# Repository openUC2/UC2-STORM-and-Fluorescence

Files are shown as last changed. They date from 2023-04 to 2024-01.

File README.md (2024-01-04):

# U.C.*STORM*
---

**Overview:**
Fluorescence microscopy is pivotal in life sciences. However, the high cost and complexity of advanced equipment limit its widespread adoption. While open-source scientific hardware offers promising solutions, they often compromise on image quality. To bridge this gap, we introduce the UC2 microscopy toolbox.

**Key Features:**
- **Cost-Effective & High-Quality**: Integrates affordable components with state-of-the-art electronics and software for top-notch fluorescence microscopy.
- **Versatile Imaging**: Achieves high-resolution fluorescence imaging for both fixed and live samples. Enables long-term live-cell imaging when placed in an incubator.
- **Advanced Imaging Capabilities**: Attains single molecule sensitivity, supports single particle tracking, and SMLM super-resolution microscopy experiments within cells.
- **Open-Source Software**: Delivers high-quality scientific data generation for both novices and experts at a fraction of commercial system costs.

**Impact & Use Cases:**
Ideal for laboratories with budget constraints, this cost-effective solution matches the capabilities of pricier commercial systems. Moreover, its affordability and ease of use make it an excellent teaching tool for students.

This repository will help you to build *a widefield fluorescence microscope and show you how to upgrade it to perform advanced microscopy methods, such as (d)STORM*.

## Cite this article

You can find the article currently as a [biorxiv Preprint](https://doi.org/10.1101/2023.05.31.542706):

```
An open-source, high resolution, automated fluorescence microscope
Ando C. Zehrer, Ana Martin-Villalba, Benedict Diederich, Helge Ewers
bioRxiv 2023.05.31.542706; doi: https://doi.org/10.1101/2023.05.31.542706
```

## How does it look like?

## 3D View

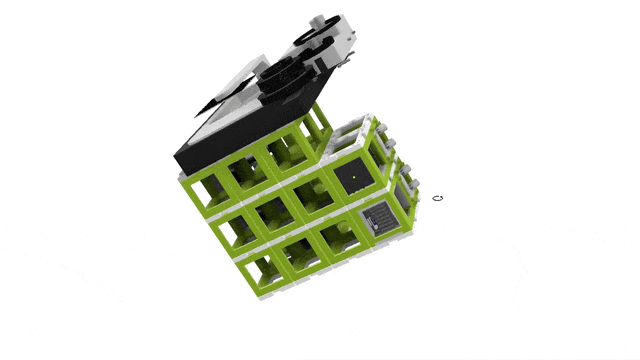
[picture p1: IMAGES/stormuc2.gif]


### Top View

<p align="center">
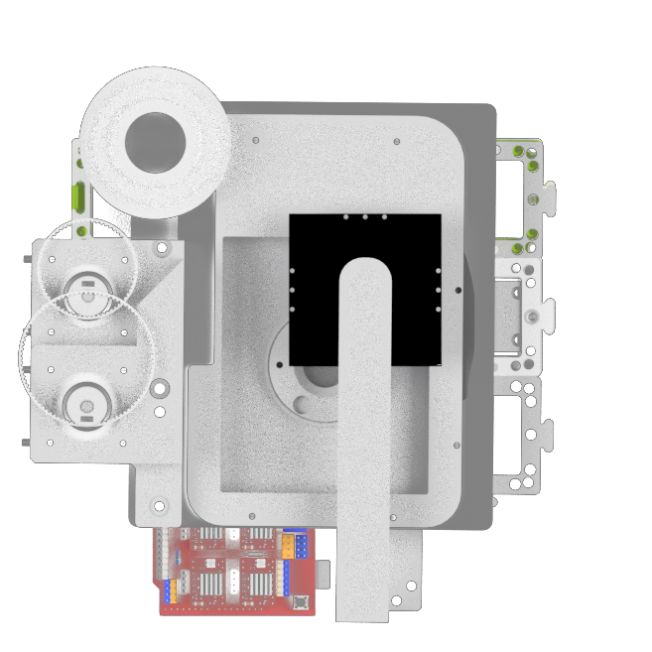
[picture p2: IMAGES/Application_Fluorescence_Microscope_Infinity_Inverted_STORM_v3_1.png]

</p>

### Side View

<p align="center">
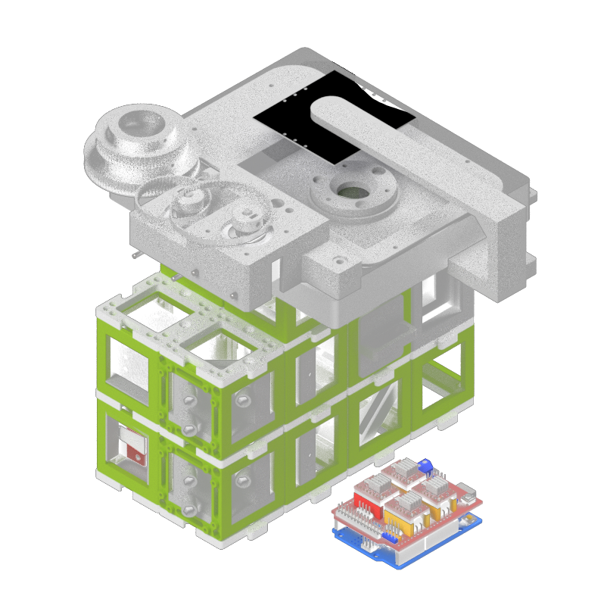
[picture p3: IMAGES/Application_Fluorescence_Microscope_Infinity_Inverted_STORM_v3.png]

</p>

***Features:***
* Single-channel fluorescence imaging
* Bright-field imaging
* XYZ motorized automated microscopy
* LED Matrix for quantitative imaging
* Steering fully integrated into ImSwitch

## Assembly

Certainly! The instructions you provided seem like a comprehensive guide to building a single molecule localization microscope using the modular optical system UC2. Below, I've expanded on a few aspects to ensure that the steps are clear and more detailed, providing information about some safety precautions, required materials, and additional tips.

### Possible to assemble in <2 Minutes 


Obviously, adjusting the lenses and mirrors, as well as adapting self-made 3D printed parts will take some time. However, the framework of the microscope is rapid and simple to build. The cubes can simply be stuck together to get the outlay of the microscope in few minutes. This allows to swiftly exchange modules, make changes and even replace components.

### Microscope Building Instructions


**Building the UC2 widefield microscope: a.** Photograph of the finished setup. **b.** Photograph of all single pieces of the dismanteled setup. The bill of materials lists all these components, including CAD files for the 3D printed parts. **c.** Emission pathway of the microscope. **d.** Stability increased by using a layer of puzzles below and above the cubes. **e.** CAD schematic of the emission pathway. **f.** Excitation pathway of the microscope. **g.** Excitation layer is also covered by a puzzle layer. **h.** CAD schematic of the excitation pathway. **i.** Z-stage photograph and corresponding CAD file. **j.** Empty cubes work as place-holder between the excitation layer and the microscope stage. **k.** The objective is screwed into the objective holder. **l.** By wiring the electronica the stage is ready to use and the microscope functional (see photograph in **a.**).



#### 0. Introduction and Precautions

Before we begin, make sure that you are working in a well-ventilated area and wearing appropriate safety gear, such as goggles and gloves. Handling lasers requires caution, so follow the manufacturer's guidelines and take necessary safety measures.

#### Materials and Tools Needed:

- UC2 modular optical system components
- Camera with the compatible mounting system
- Achromatic lens with a suitable mount
- 3D printer (for creating mounts)
- Thorlabs 20mm tube or equivalent
- Laser with adaptable profile
- Convex lenses
- Diffuser (cling foil, etc.)
- Motor-driven translation stage
- 3D printed gears and timing belts
- Commercial XY stage
- 4-well/8-well chambers and circular 18 mm/25 mm cover glass holders
- Alignment tools, such as apertures
- LED for top-light illumination
- Various screws, bolts, and tools for assembly
- Protective gear for handling lasers and other delicate components

#### 1. Detection Layer

The schematic of the layer and the actual composition can be seen in the **setup building figure**.
The camera is positioned within a cube, so that the camera chip is
centered. At a distance of 100 mm, the tube lens is positioned on the
same optical axis. As a cube is 50 mm broad, an empty cube is placed
between the camera and the lens. A 3D printed mount is combined with a
Thorlabs 20 mm tube, to which a mounted achromatic lens can be screwed
to the tube. The 3D printed mount is thick enough to not tilt while
still being movable. The 3D printed mount holding the lens is moved to
focus an object on the camera. The mirror can be placed in front of the
camera or before the tube lens. The mirror is tiltable along two axes.
The emissions from the objective are parallel. The distance can be
chosen accordingly to the build. A mirror tilted by 45 degrees reflects
the vertical emissions of the sample into the tube lens and subsequently
onto the camera.
<!---
![](./IMAGES/image1.png)

Emissions from the objective are reflected by the mirror, focused by the
tube lens, displaced with the tiltable mirror and imaged on the
detector.
--->
#### 2. Laser

The laser profile can be tuned to match the application the microscope
will be used for. When imaging a Chroma red fluorescent slide, the laser
profile can be characterized, and possible variations or inhomogenities can be removed.
Without any modification, the laser only
illuminates a subset of the field of view. By adding a telescope build,
the laser beam is magnified. The modifications proposed in the **Illumination** section show different illumination patterns, leading to different possible imaging modalities.

<!---
![](./IMAGES/image2.png)

![](./IMAGES/image3.png)

![](![](./IMAGES/image4.png)

![](![](./IMAGES/image5.png)

Here, the lens l1 is focusing onto the rotating cling foil. The diffused beam is magnified by the lens l2. The
resulting beam profiles can be seen in following images:

The laser beam without magnification (left) has a smaller spot with high
laser intensity. The illumination is not homogeneous but can be
advantageous for applications needing higher laser densities. The laser
profile with a 2 times magnification (middle) and the magnification with
diffuser (right) enable homogeneous illumination of most of the field of
view.
--->
##### Tips:

- Ensure that the diffuser is balanced properly to avoid vibrations that might affect the image quality.
- Calibration of the laser profile according to the application is crucial. Make sure to test different magnifications and diffusions.

#### 3. Excitation Layer

The laser emission can be chosen accordingly. The laser beam is then
focused by a lens into the back focal plane of the objective (here after
the filter cube in a higher vertical plane). Through a tiltable mirror,
the beam can be positioned into the center of the field of view. The
filter cube has filters adapted to the laser and the fluorophores used
in the experiments. The mount for the laser, the lens, the mirror as
well as the filter cube can all be 3D printed. The schematic and actual photograph of the layer within the setup are shown in the **setup building figure**.
<!---
![](./IMAGES/image6.png)
--->

##### Tips:

- Ensure that all 3D printed components fit perfectly with the rest of the parts.
- The choice of filters must correspond with the laser and the fluorophores used in the experiments.

#### 4. Z Stage
<!---
![](./IMAGES/image7.png)
--->
The z stage is a motor driven translation stage. The
stage is embedded into a 3D printed case to make the dimensions fit the
cube design. A puzzle piece on the top and in the bottom allow to build
a stable connection between the stage and the rest of the microscope. A
3D printed objective holder connects the stage to the objective. It is
advised to print the objective holder with a high percentage of infill
and a stable plastic, as the heavy objective causes strain on the
material.

##### Tips:

- Careful selection of the material for the objective holder is crucial to withstand the weight and strain.

#### 5. XY Stage

The XY stage used in the current build is a commercial solution. The
manual translation knobs were equipped with 3D printed gears. In order
to motorize the stage, motors which were also equipped with gears
transmitted the torque to the stage via timing belts. These were printed
with a softer and thus more elastic plastic. The whole stage is attached
to the rest of the microscope via a 3D printed plate, working as a
replacement for a puzzle layer, with the according perforations where
connections to the top layer of cubes was provided. Furthermore, the
stage needs a 3D printed insert, to hold the sample. Models for
4-well/8-well chambers and circular 18 mm/25 mm cover glass holders are
available. An alternative where the coverglass is directly embedded into
the 3D printed sample holder is also provided.

##### Tips:

- Calibration and testing of the XY stage should be done to ensure smooth and accurate movement.

#### 6. Alignment Procedure

To align the optics, the first step is to position all optics along the
optical axis and ensure that they are not tilted. To make this procedure
more systematic, the excitation pathway is aligned with an aperture,
which is placed between the second lens of the telescope build and the
lens focusing the laser in the back focal plane of the objective. While
imaging a fluorescent slide, an almost closed aperture is placed to
match the maximum of the laser excitation. This allows to know the
position of the laser within the sample. The emission pathway is then
adjusted to have the aperture in the center of the field of view. This
way, the maximal laser intensity spot is in the center of the field of
view, which should both theoretically be along the optical axis.

##### Tips:

- Proper alignment is essential for obtaining accurate results. Take your time and follow systematic procedures.
- Specialized alignment tools and techniques might be needed for precise adjustments.

#### 7. Top Light Illumination

The illumination for bright-field imaging needs to be spatially
invariant in relation to the objective. It is important to attach the
top-light illumination to the main body of the microscope instead of the
XY stage. This is achieved by attaching an LED to a 3D printed arm,
connected to the highest puzzle layer, thus decoupled of the possible
motions of the XY-stage.

##### Tips:

- The brightness of the LED should be adjustable to suit various imaging requirements.
- Consider using a diffuser to create more uniform illumination across the sample.

### Conclusion

Building a single molecule localization microscope with the modular optical system UC2 is an exciting and challenging project. This guide provides a step-by-step approach to construct the microscope and align its various components. Always remember to follow safety precautions and consult manufacturer's guidelines or a professional if you are unsure about any step.

Feel free to share your progress and ask questions on GitHub or other platforms, as the scientific community can be of great assistance in such projects.

Happy building!

## Bill of material

Below you will find all components necessary to build this device

### 3D printing files

All these files need to be printed. We used a Prusa i3 MK3S using PLA Prusament (Galaxy Black) at layer height 0.15 mm and infill varying between 20-40 %, depending on how much weight rests on the 3D printed part. For applications within the incubator, the use of ABS Prusament is recommended, as the thermal stability is noticeably increasing the setups stability, especially with increased working temperature and humidity. The layer height and the infill can be chosen identically for ABS as for PLA parts.

An in-depth tutorial on how to build the XY-stage can be found here https://github.com/openUC2/

An in-depth tutorial on how to build the Z-stage can be found here https://github.com/openUC2/

| Printed  | UC2 | Linear Stage mount | 00_Linear_Stage_NEMA11_Mount.ipt | 1  | $5.00 | 5 |
|---|---|---|---|----|---|-----|
| IM | openUC2 | openUC2 IM Cube | 10_Cube_1x1_IM.ipt | 42 | $5.00 | 210 |
| IM | openUC2 | UC2 Puzzle piece | 10_Base_puzzle_v3.ipt | 26 | $5.00 | 130 |
| Printed  | UC2 | Linear Stage spacer | 00_Linear_Stage_NEMA11_Mount_Lid.ipt | 1  | $1.00 | 1 |
| Printed  | UC2 | UC2 objective Mount linear stage | 20_Cube_Insert_Cube_Z-Stage_NEMA11_china_objectivemount_v3.ipt | 1  | $1.00 | 1 |
| Printed  | UC2 | UC2 Insert for Kinematic Mirror Part1 | 20_Cube_Insert_Kinematic_Mirrormount_45_base_part1.ipt | 3  | $5.00 | 15  |
| Printed  | UC2 | UC2 Insert for Kinematic Mirror Part2 | 20_Cube_Insert_Kinematic_Mirrormount_45_base_part2.ipt | 3  | $1.00 | 3 |
| Printed  | UC2 | Adapter for Nut | 30_Adapter_M3_nut.ipt | 9  | $1.00 | 9 |
| Printed  | UC2 | UC2 Insert for 1 inch Mirror, 45° | 20_Cube_Insert_Kinematic_Mirrormount_45_Thorlabsadapter.ipt | 3  | $5.00 | 15  |
| Printed  | UC2 | UC2 Insert for standard C-mount | 20_Cube_Insert_Cmount_v3.ipt | 1  | $5.00 | 5 |
| Printed  | UC2 | UC2 Insert for Thorlabs Cage | 20_Cube_Insert_Thorlabs_Pins.ipt | 2  | $5.00 | 10  |
| Printed  | UC2 | UC2 Insert for Thorlabs 1inch lens | 20_Cube_Insert_Thorlabs_SM1Tube.ipt | 2  | $5.00 | 10  |
| Printed  | UC2 | Filtermount | 30_Cube_Insert_Filter_Revolver_Filter_base_single_v3.ipt | 1  | $5.00 | 5 |
| Printed  | UC2 | UC2 Insert for Allied Vision Camera | 30_XYTabel_Aliexpress_basplateadapter.ipt | 1  | $7.00 | 7 |
| Printed  | UC2 | Motormount for XY Stage | 30_XYTable_Aliexpress_motormount.ipt | 1  | $7.00 | 7 |
| Printed  | UC2 | Sample Inset for XY Stage | 30_XYTable_Aliexpress_sampleinsert_round.ipt | 1  | $7.00 | 7 |
| Printed  | UC2 | Timing Gear Small | 00_XYTable_medium_gear.ipt | 1  | $2.00 | 2 |
| Printed  | UC2 | Timing Gear Large | 00_XYTable_large_gear.ipt | 1  | $2.00 | 2 |
| Printed  | UC2 | Printed Timing Belt Long | 00_GT2_TimingBelt_flexible_Modular_xytable_large_89tooth.ipt | 1  | $5.00 | 5 |
| Printed  | UC2 | Printed Timing Belt Short | 00_GT2_TimingBelt_flexible_Modular_xytable_large_65tooth.ipt | 1  | $5.00 | 5 |
| Printed  | UC2 | Holder for LED Array | 40_Cube_XY_Table_Illumination_Arm.ipt | 1  | $5.00 | 5 |
| External | Adafruit | Adafruit 64 LED array (8x8) | 00_LED-ARRAY.ipt | 1  | $20.00  | 20  |
| External | Chroma | Chroma ET655 | 00_Chroma_ET655lp long-pass.ipt | 1  | $250.00 | 250 |
| External | Chroma | Chroma ZET 636 | 00_Chroma ZET635_Excitationfilter.ipt | 1  | $250.00 | 250 |
| External | Chroma | Chroma ZT640 | 00_Chroma_ZT640rdc.ipt | 1  | $250.00 | 250 |
| External | Any provider | Linear Stage 50mm , Nema 12, MGN9h | | 1  | 50 | 50  |
| External | Any provider | 5 mm Neodym Magnets | 00_BallMagnets_5mm_single.ipt | 9  | | 0 |
| External | Thorlabs | Thorlabs PF 10-03-P01 | 00_Thorlabs_PF10-03-P01-Step.ipt | 3  | $25.00  | 75  |
| External | Allied Vision | Allied Vision Alvium USB 3.1 Kamera 1800 U-158m, 1/2,9", 1,58 MP, C-Mount, monochrom | *Varies* | 2  | $445.00 | 890 |
| External | | C:\cad\PSP2011Client\Work\139705407318IP01941702.stp | 00_Basler_ace_USB3_C-Mount.ipt | 1  | | 0 |
| External | Würth | DIN 912 - M3 x 0.5 x 12 x 10.75.ipt | DIN 912 - M3 x 0.5 x 12 x 10.75.ipt | 15 | $1.00 | 15  |
| External | Thorlabs | Thorlabs AC254-050-A-ML | 00_THORLABS_AC254-050-A-ML-Step.ipt | 2  | $100.00 | 200 |
| External | Thorlabs | Thorlabs CP33 | 00_Thorlabs_Cage_CP33_M.ipt | 2  | $20.00  | 40  |
| External | Euromex | Euromex Mechanischer 180 x 155 mm Objekttisch mit integriertem 75 x 55 mm X-Y-Kreuztisch und transparenter Glasplatte, NZ.9505 | 00_XYTable_china_75_55mm.ipt | 1  | $200.00 | 200 |
| External | Robot kit | GT2 pulley 16 teeth 4mm bore for 6mm timing belt | 00_XYTable_pulley.ipt | 2  | $2.00 | 4 |
| External | Laserlands.net  | 638nm Red Laser Module 500mW Round Dot Focusable TTL 3050 | 00_LASER_640nm.ipt | 1  | $40.00  | 40  |

### Design files

The original design files are in the [INVENTOR](./INVENTOR) folder.

## Showcase
The compact size of the setup and the modular character allow to adapt the setup to any incubator. ImSwitch can be started from any given compute ror laptop. Simple USB cables connect the microscope to the outside (computer) for full control over its functionalities.
Here you can see the device in action:

<p align="center">
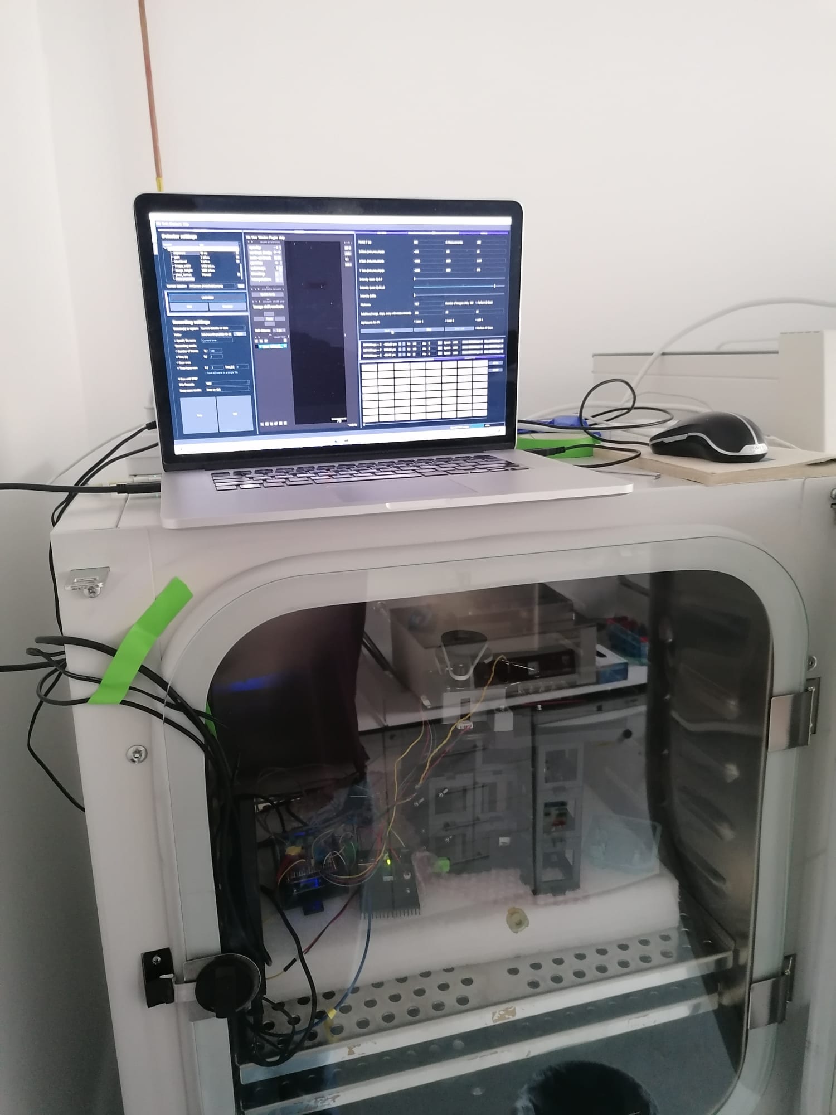
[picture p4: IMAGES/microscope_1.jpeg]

</p>gith

Example of the setup being used within a cell culture incubator for continuous imaging of cells.

<p align="center">
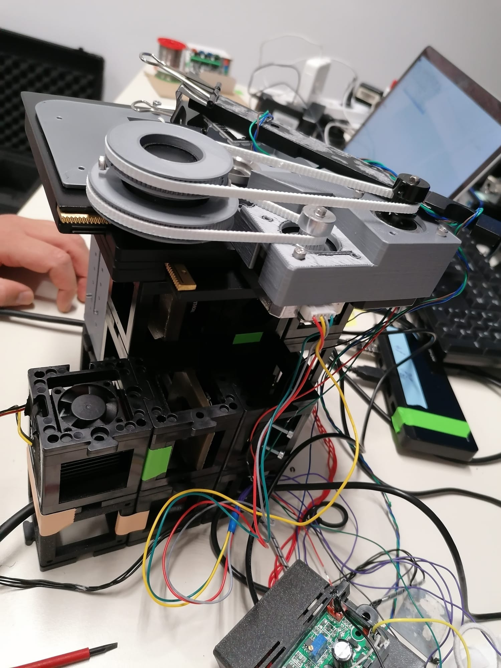
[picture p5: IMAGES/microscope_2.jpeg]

</p>

<p align="center">
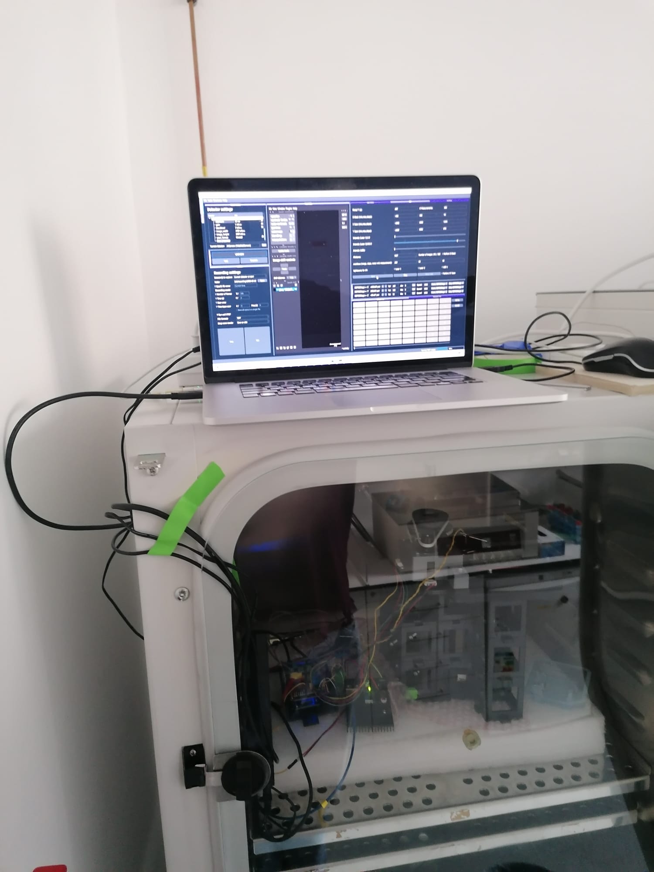
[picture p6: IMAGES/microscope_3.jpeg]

</p>

<p align="center">
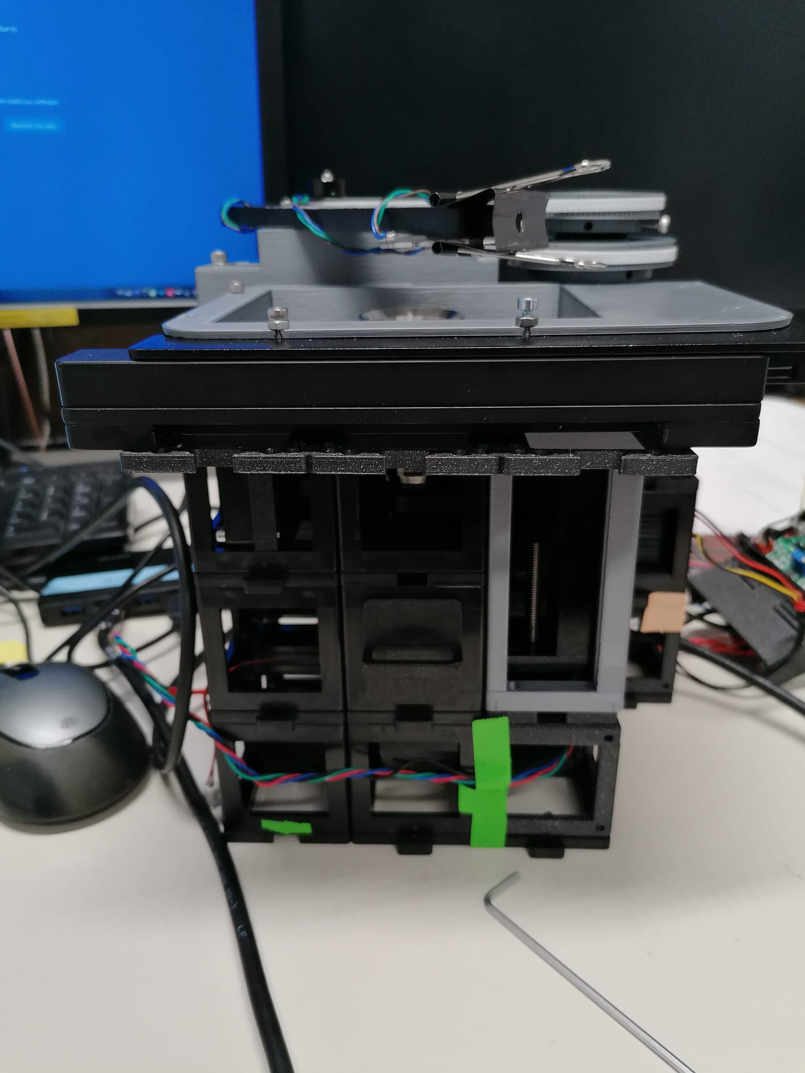
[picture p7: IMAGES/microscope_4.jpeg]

</p>

<p align="center">
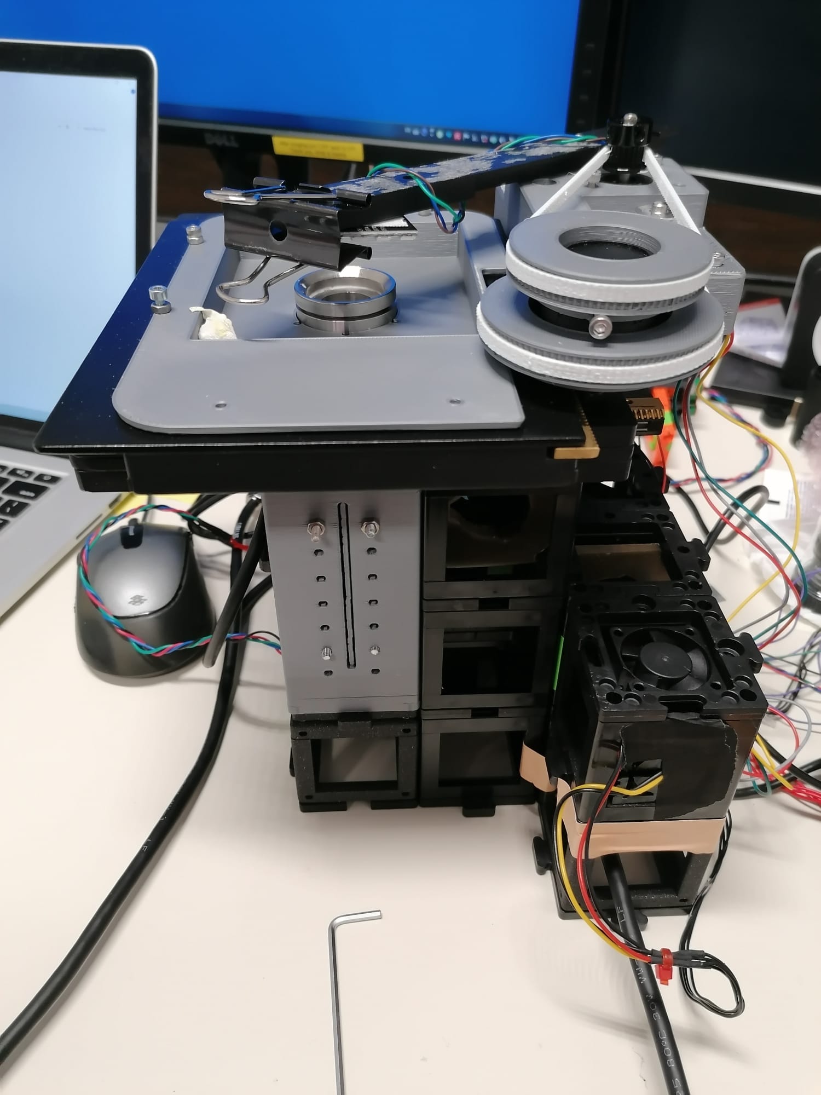
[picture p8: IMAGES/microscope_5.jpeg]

</p>

<p align="center">
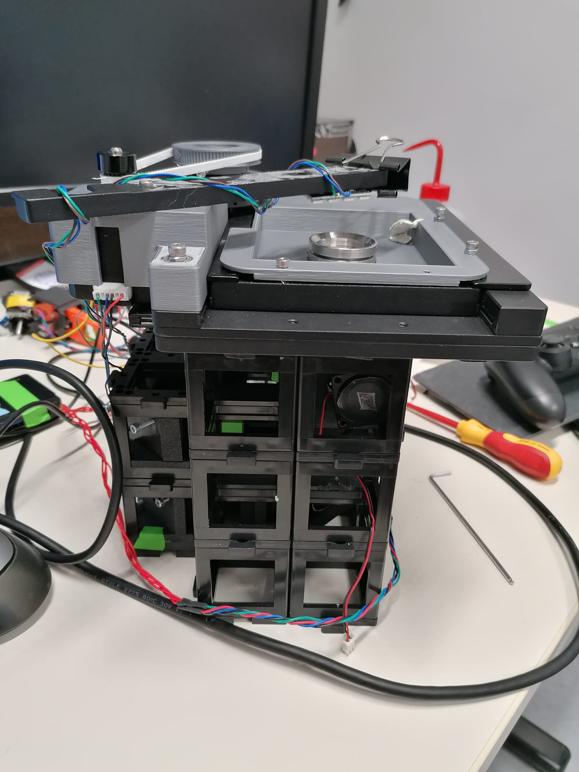
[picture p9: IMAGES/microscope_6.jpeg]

</p>

## Mechanical stability of the setup

See the mechanical stability section of the repository.

## Wide-field imaging, Live-cell imaging, Single molecule applications

See the Results section of the repository.

## Get Involved

This project is open so that anyone can get involved. You don't even have to learn CAD designing or programming. Find ways you can contribute in  [CONTRIBUTING](https://github.com/openUC2/UC2-GIT/blob/master/CONTRIBUTING.md)

## License and Collaboration

This project is open-source and is released under the CERN open hardware license. Our aim is to make the kits commercially available.
We encourage everyone who is using our Toolbox to share their results and ideas, so that the Toolbox keeps improving. It should serve as a easy-to-use and easy-to-access general purpose building block solution for the area of STEAM education. All the design files are generally for free, but we would like to hear from you how is it going.

You're free to fork the project and enhance it. If you have any suggestions to improve it or add any additional functions make a pull-request or file an issue.

Please find the type of licenses [here](https://github.com/openUC2/UC2-GIT/blob/master/License.md)

REMARK: All files have been designed using Autodesk Inventor 2019 (EDUCATION)

## Collaborating
If you find this project useful, please like this repository, follow us on Twitter and cite the webpage or the publication! :-)

<!---
# Unsorted Images
![](./IMAGES/Application_Fluorescence_Microscope_Infinity_Inverted_STORM_v3.png)
![](./IMAGES/Application_Fluorescence_Microscope_Infinity_Inverted_STORM_v3_1.png)
![](./IMAGES/Folie1.png)
![](./IMAGES/image1.png)
![](./IMAGES/image2.png)
![](./IMAGES/image3.png)
![](./IMAGES/image4.png)
![](./IMAGES/image5.png)
![](./IMAGES/image6.png)
![](./IMAGES/image7.png)
![](./IMAGES/IMG_20200803_092845.jpg)
![](./IMAGES/IMG_20200803_093507.jpg)
![](./IMAGES/IMG_20200803_093543.jpg)
![](./IMAGES/IMG_20200803_094150.jpg)
![](./IMAGES/IMG_20200803_124932.jpg)
![](./IMAGES/IMG_20200807_181322.jpg)
![](./IMAGES/IMG_20200807_181333.jpg)
![](./IMAGES/IMG_20200807_181517.jpg)
![](./IMAGES/IMG-20200803-WA0003.jpeg)
![](./IMAGES/microscope_1.jpeg)
![](./IMAGES/microscope_2.jpeg)
![](./IMAGES/microscope_3.jpeg)
![](./IMAGES/microscope_4.jpeg)
![](./IMAGES/microscope_5.jpeg)
![](./IMAGES/microscope_6.jpeg)
![](./IMAGES/STORM.gif)

![](./IMAGES/UC2_STORM.png)
![](./IMAGES/SetupImages_1.jpeg)
![](./IMAGES/SetupImages_2.jpeg)
![](./IMAGES/SetupImages_3.jpeg)
![](./IMAGES/SetupImages_4.jpeg)
![](./IMAGES/SetupImages_5.jpeg)
![](./IMAGES/SetupImages_6.jpeg)
--->

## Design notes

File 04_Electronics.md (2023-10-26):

# Electronics

Here we make use of the ESP32 Wemos D1 R32 microcontroller board in combination with the CNC Shield v3. The wiring of the different components is straight forward as the Stepper Motors are attached to the stepper drivers and the Laser is triggered by the `SpinEn` pin. The NeoPixel LED mounts to the  `Hold` pin.



## Flashing the firmware

Go to the website https://youseetoo.github.io/ and choose the CNC board as the hardware configuration to flash the latest version of the Firmware. The PS3 controller's MAC address has to be setup with the PS Pairing tool. The actual MAC Address is printed out on the Serial monitor while the Board is booting up.

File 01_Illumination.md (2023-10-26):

# Setting up the laser

## Laser illumination

Illuminating the sample can be done with different lasers. In the here
presented setup, the laser illumination is provided by the 638nm Red
Laser Module 500mW Round Dot Focusable TTL 3050 (acquired on
lasernets.com). In order to perform imaging assays needing high laser
intensities, the laser path remains unchanged (see excitation pathway
figure) to maximize the photon density at the sample plane. The optional
beam magnifier combined with a diffuser enables to have a more even and
homogenized illumination across the field of view, which is more
desirable for imaging assays with lower requirements in terms of laser
density.

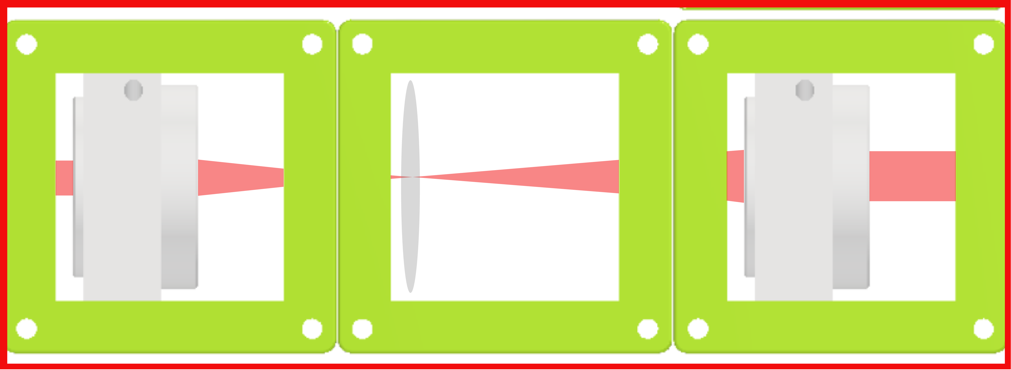
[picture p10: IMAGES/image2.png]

The telescope is built by placing two
convex lenses in a distance equal to the sum of their focal distances in
the light path. The magnification can then be calculated by the ratio of
the focal lengths (e.g. f1 = 3\*f2 magn. = 3x). If the beam is not
homogeneous or does not have a smooth profile or patterns that vary over
time, the beam can be homogenized through diffusing the light in the
common focal point of both telescope lenses. The diffuser can be as
simple as a cling foil, attached to a rotor or a fan motor and spinning
the foil.

A photograph of the construction consisting of a telescopic lens arrangement with a
diffusor rotating in the focal point of both lenses is showed in the figure below. A simplified
version can be built by combining a fan, where the rotor blades have
been removed, with a piece of cling foil as diffusing material.

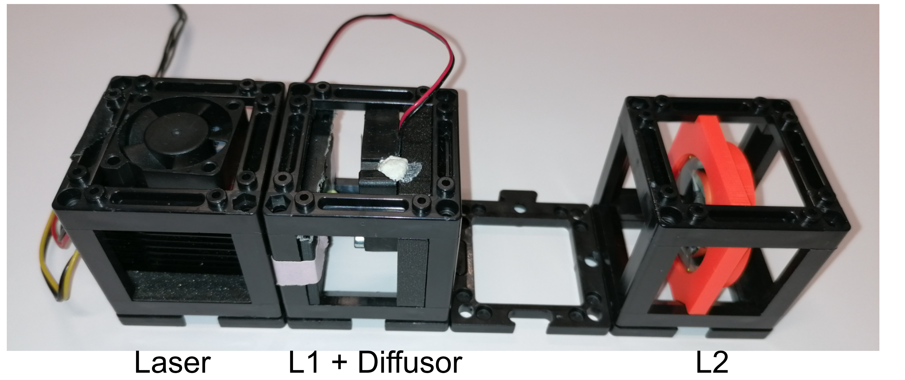
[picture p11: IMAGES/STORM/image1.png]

*Fig. 1: telescope build with diffuser (rotating cling foil)*

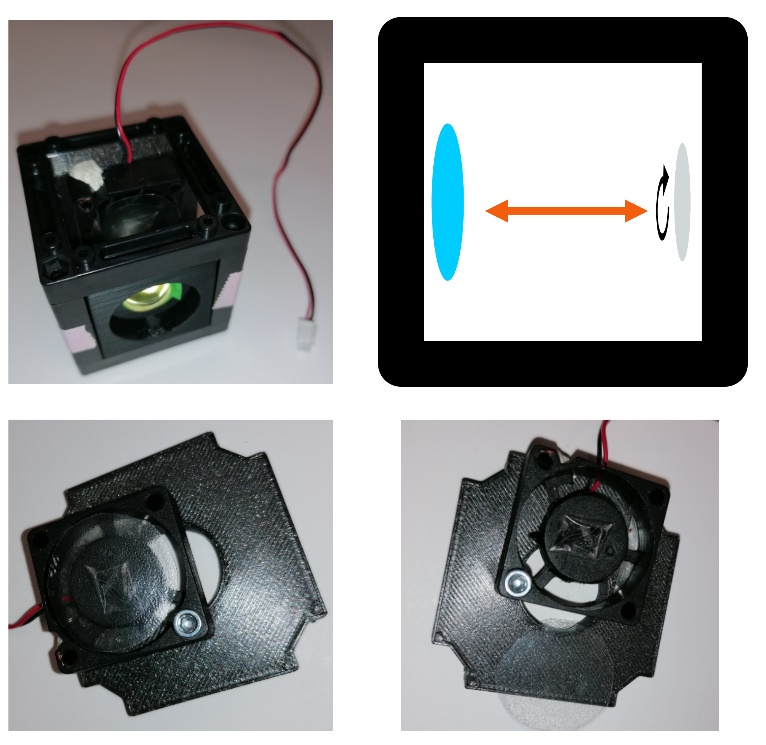
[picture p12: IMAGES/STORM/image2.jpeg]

*Fig. 2: Within the cube containing L1 and the diffusor, the distance between
both matches the focal length of L1. For different magnification, they
can also be placed within two different cubes. The diffusor itself is
attached to a regular UC2 cube mount. The position of the fan is not
important, as long as the light path is not blocked. The cling foil is
simply stuck to the fan center with a piece of tape.*

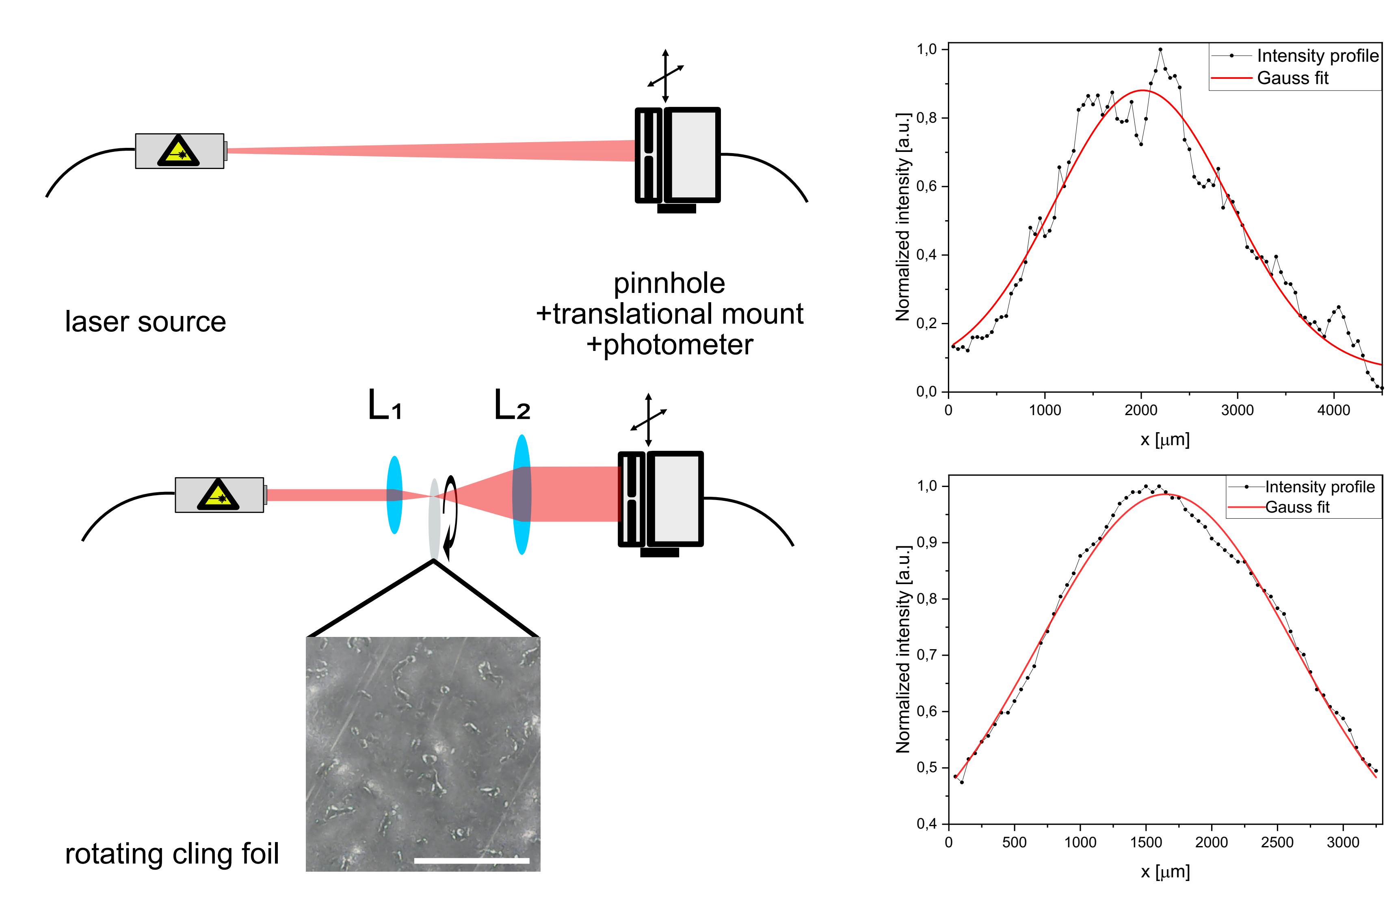
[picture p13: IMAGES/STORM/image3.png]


Fig. 3: Difference in laser profile using the diffusor and telescopic
lens. The profile has been measured by shifting a photometer covered by
a pinhole across the laser spot. The distances between the components on
the schematics (left) are not up to scale. The scale bar in the image
showing the cling foil surface represent 1mm.

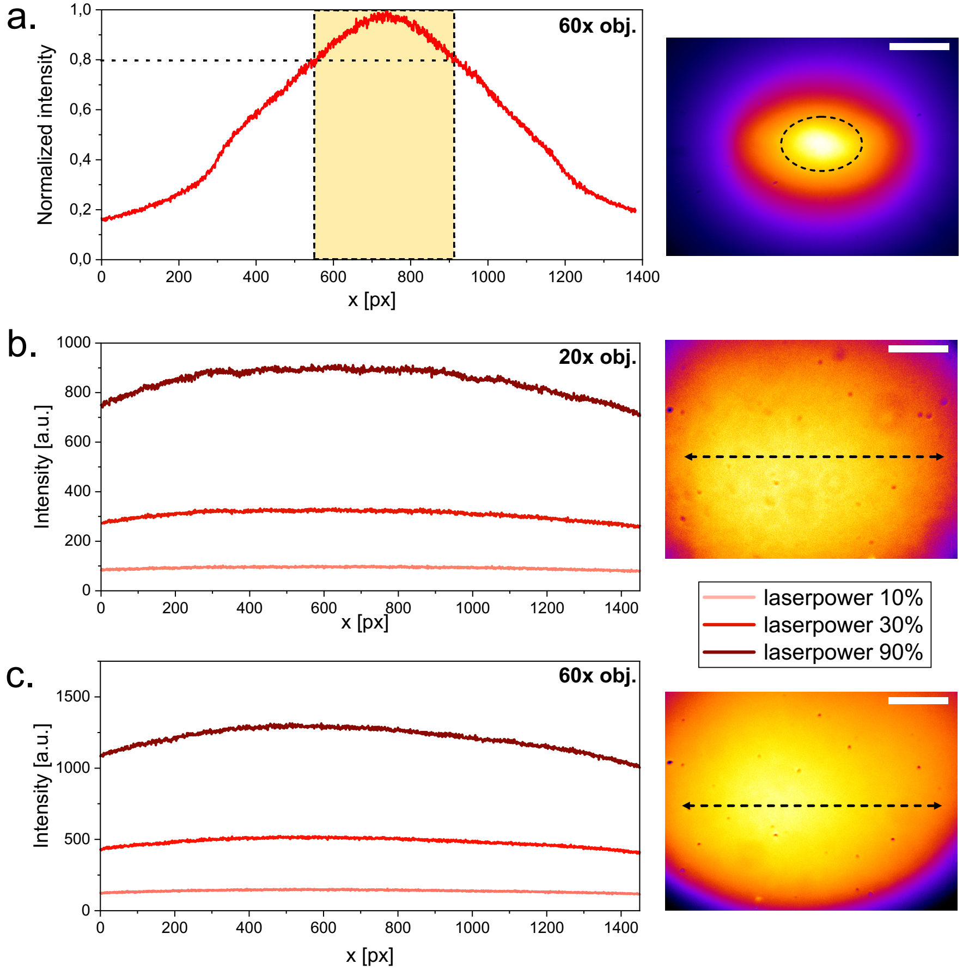
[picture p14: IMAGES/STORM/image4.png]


*Fig. 4: Illumination profile as measured on a fluorescent far red Chroma
slide at the sample plane. Illumination of the laser itself using a 60x
objective (a.), of the laser combined with diffusor, telescope and a 20x
objective (b.), of the laser combined with diffusor, telescope and a 60x
objective (c.). The graphs on the left represent the horizontal profile
of the illumination. The images on the right represent the complete
field of view, with scale bars representing 30 µm for the 60x and 90 µm
for the 20x objective.*

## Filtering Illumination

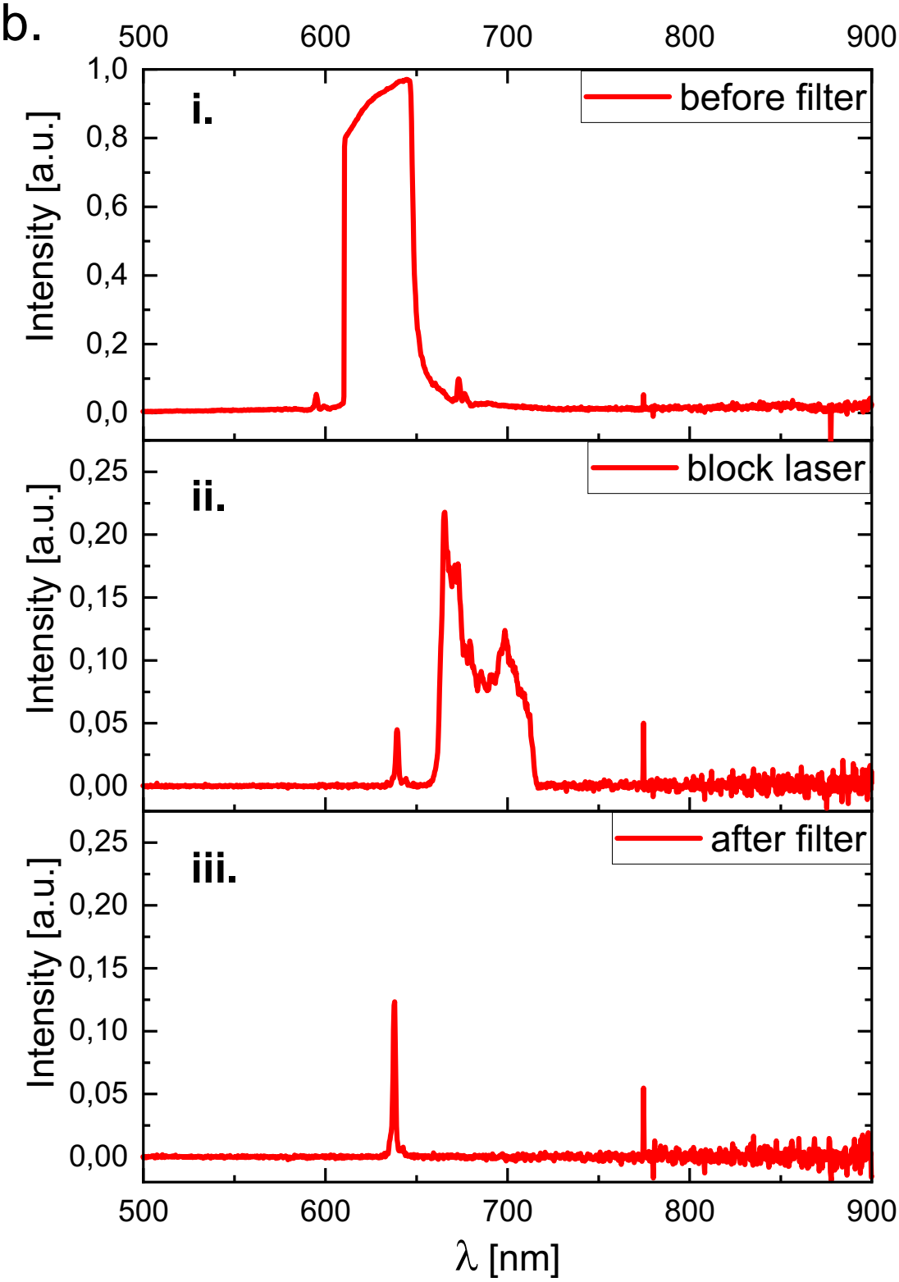
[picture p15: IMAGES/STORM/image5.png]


Spectrum of the laser emission measured at the sample plane **i.**
without any filter, **ii.** with a filter only blocking the laser-line,
**iii.** with a combination of emission filter and excitation filter.

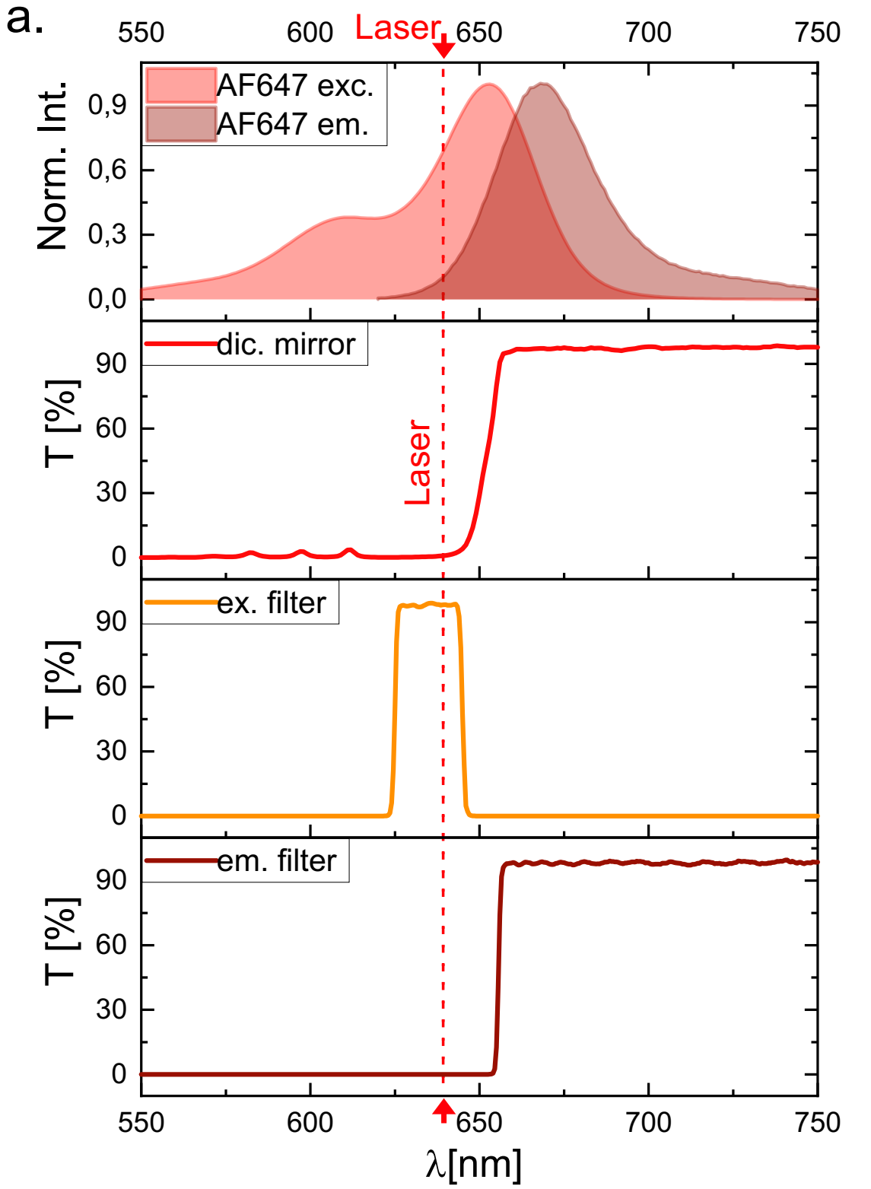
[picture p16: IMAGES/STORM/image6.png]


Absorption and emission spectrum of AF647, spectra of the dichroic
mirror (Chroma ZT640rdc), the excitation filter (Chroma ZET635/20x EX),
and the emission filter (for λ &gt; 655 nm, Chroma ET655lp long-pass).

## Illumination with a fiber coupled laser

The usage of a simple laser which can be adapted according to the
experimental needs is a solution which makes the setup adaptable and
allows users to perform different assays without acquiring additional
hardware. For microscopy applications where high laser intensities
applications are not necessary, the use of a fiber coupled laser might
be a practicable alternative for the illumination. Laser beams emanating
from a single mode fiber have a gaussian profile which should be free of
speckles and interferences. The fiber also has advantages in terms of
laser safety and simplicity of usage as it can be combined to various
commercially available cage and tube systems.

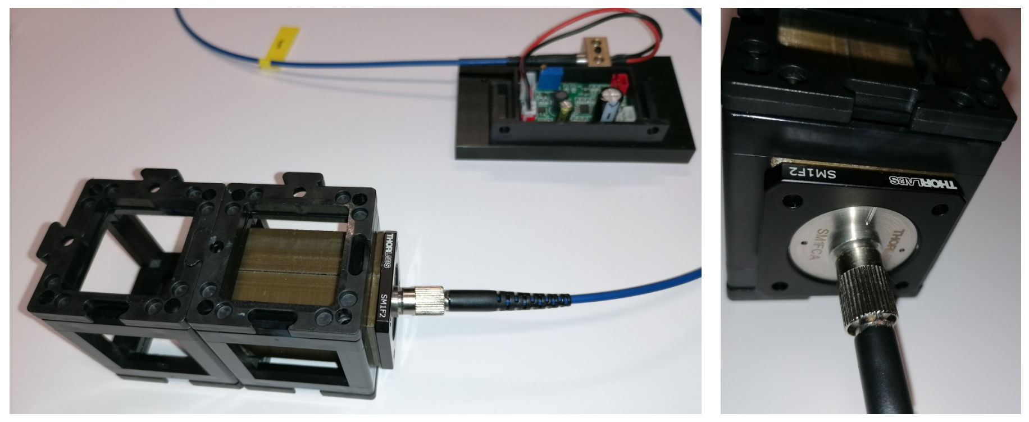
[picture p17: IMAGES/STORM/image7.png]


Fig. 5: Fiber illumination module.

![](./IMAGES/STORM/image8.png" style="width:4.8in;height:3.27936in" />

Fig. 6: The fiber is aligned to the optical axis by coupling the fiber
to a tube system, which is adapted to the cube dimensions via a 3D
printed cuboid with a circular hole (a). The lens (b) is connected to
the fiber adapter (d) via a tube with mounting threads (c). Length of
the tube is adapted to set the distance between the lens and the fiber
end (e) to the focal length of the lens (b, here 50 mm).

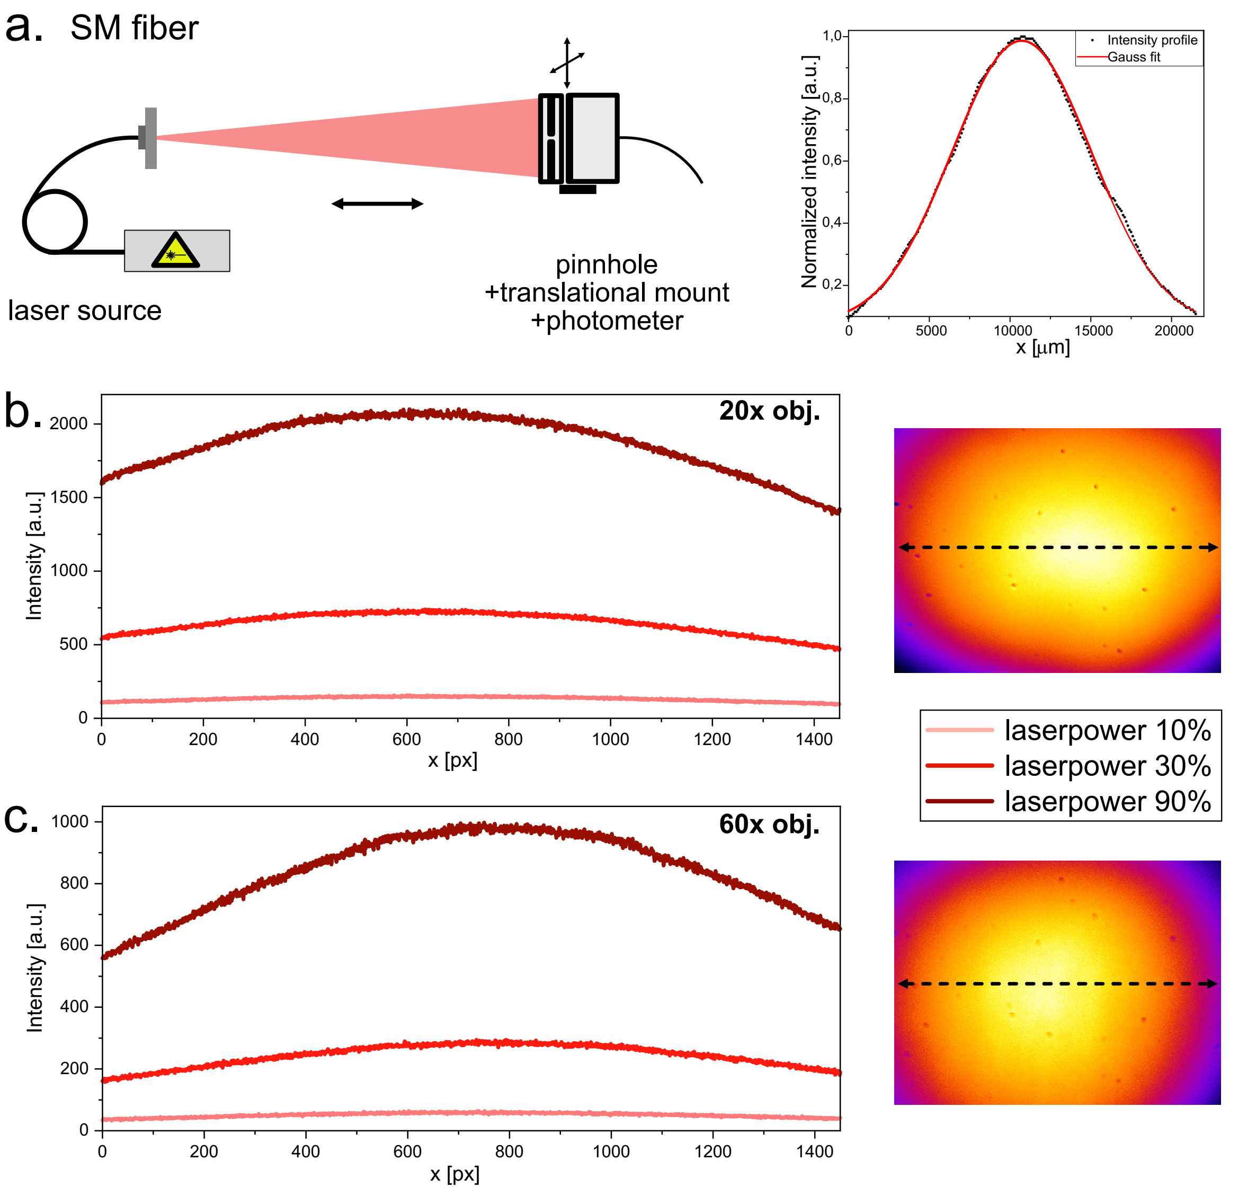
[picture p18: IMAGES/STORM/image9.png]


Fig.7: Characterization of the fiber laser illumination. a. Laser
profile measured by shifting a photometer covered by a pinhole across
the laser spot. The illumination is further characterized by imaging a
far-red fluorescent Chroma slide with a 20x and a 60x objective. The
horizontal line profiles (left) represent the dotted line on the images
of the field of view (right).

## Top light illumination

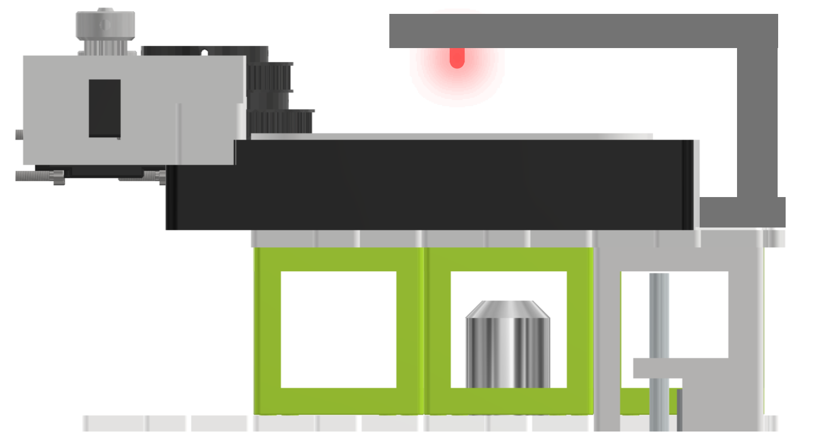
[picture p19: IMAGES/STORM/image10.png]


Fig. 8: Top light illumination via a 3D printed arm holding a red (635
nm) LED. Alternatively, a high-power white LED or an LED array can be
used as top-light illumination.

<!---
## Imaging with the UC2-STORM setup

![](./IMAGES/STORM/image12.png)

Widefield images of CV-1 cells immune-stained against tubulin, at
different magnifications using the UC2 microscope. **a.** 60x objective,
scale bar represents 30 µm. Two regions of interest have been zoomed in
to demonstrate the ability to detect and characterize single
microtubules. **b.** 40x objective, scale bar represents 45 µm. **c.**
20x objective, scale bar represents 90 µm.

![](./IMAGES/STORM/image13.png)

Widefield images of immune-stained clathrin coated pits (left),
immune-stained tubulin (middle) and SiR Actin stain of CV-1 cells with
the UC2 setup and a 60x objective. Scale bar represents 25 µm.

![](./IMAGES/STORM/image14.png)

Live cell imaging of CV-1 cells stained with SiR actin over a period of
five hours.

![](./IMAGES/STORM/image15.png)

Live cell imaging of T98G cells stained with SYTO far red nucleic dye
over a period of two days within an incubator.

![](./IMAGES/STORM/image16.png)

Single particle tracking of GPI-GFP on HeLa cells. For more
photostability, the tracks are acquired by imaging quantum dots. These
have been functionalized with straptavidin and are attached to GFP via
biotin conjugated anti-GFP nanobodies. The construct is schematically
disaplayed in **a.** The acquired tracks are overlayed on a bright-field
image of the HeLa cells (**b.**) (scale bar represents 10 µm). Two
single tracks are exeplarily displayed in **c.**

![](./IMAGES/STORM/image17.png)

Diffusion coefficient of the tracked quantum dots with 10 and 25 ms
exposure time of the camera. To have similar localization uncertainties,
the laser power was doubled for the shorter exposure time. Two
populations can be identified. The first one has a slower diffusion and
corresponds to particles which are stuck or simply immobile. The other
population which seems to have a maximum around
$D = 0,1\\frac{\\text{µm}^{2}}{s}$ and corresponds to the random
diffusion of GPI on the cell membrane.

![](./IMAGES/STORM/image18.png)

*d*STORM image of microtubules reconstructed from wide-field images
acquired on the UC2. **a.** Immuno-stained microtubules in CV-1 cells
are shown in wide-field and with *d*STORM. Scale bar represents 5 µm.
**b.** and **c.** show the averaged profiles along 200 nm of
microtubules within two regions of interest. Profiles are fitted with a
double Gaussian. Peak to peak distances of (38±2) nm for **b** and
(43±2) nm for **c.i** are extrapolated. Scale bar represents 1 µm in the
magnified ROIs. **d.** Drift measured by cross-correlation during the
raw-data acquisition period of the reconstructed image displayed in
**a**. **e.** Simplified schematic of the front view of a microtubule
sample after immuno-staining and the resulting railroad tracks.

## Imaging with lower-budget objectives

![](./IMAGES/STORM/image19.png)

Stable HeLa cell-line with Clathrin light chain-GFP stained with AF647
conjugated anti-GFP nanobodies, in the fluorescence as well as the
brightfield channel. Images have been acquired with the different
objectives listed in the top of the image. The scale bars in the 20 ×,
60 × and 100 × magnified images respectively represent 30 µm.

![](./IMAGES/STORM/image20.png)

Single molecule localization microscopy (*d*STORM) on the UC2 setup with
a low-budget objective. Reconstruction of CLC-GFP in HeLa cells
immuno-stained with AF647 conjugated nanobodies. Scale bar for
represents 10 µm. Two CCPs have been zoomed in to plot the profiles
along the red transparent line. Scale bar for the magnified regions of
interest represents 200 nm.

--->

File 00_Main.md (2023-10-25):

# U.C.*STORM*
---

**Overview:**
Fluorescence microscopy is pivotal in life sciences. However, the high cost and complexity of advanced equipment limit its widespread adoption. While open-source scientific hardware offers promising solutions, they often compromise on image quality. To bridge this gap, we introduce the UC2 microscopy toolbox.

**Key Features:**
- **Cost-Effective & High-Quality**: Integrates affordable components with state-of-the-art electronics and software for top-notch fluorescence microscopy.
- **Versatile Imaging**: Achieves high-resolution fluorescence imaging for both fixed and live samples. Enables long-term live-cell imaging when placed in an incubator.
- **Advanced Imaging Capabilities**: Attains single molecule sensitivity, supports single particle tracking, and SMLM super-resolution microscopy experiments within cells.
- **Open-Source Software**: Delivers high-quality scientific data generation for both novices and experts at a fraction of commercial system costs.

**Impact & Use Cases:**
Ideal for laboratories with budget constraints, this cost-effective solution matches the capabilities of pricier commercial systems. Moreover, its affordability and ease of use make it an excellent teaching tool for students.

This repository will help you to build *a widefield fluorescence microscope and show you how to upgrade it to perform advanced microscopy methods, such as (d)STORM*.

## Cite this article

You can find the article currently as a [biorxiv Preprint](https://doi.org/10.1101/2023.05.31.542706):

```
An open-source, high resolution, automated fluorescence microscope
Ando C. Zehrer, Ana Martin-Villalba, Benedict Diederich, Helge Ewers
bioRxiv 2023.05.31.542706; doi: https://doi.org/10.1101/2023.05.31.542706
```

## How does it look like?

## 3D View



### Top View

<p align="center">

</p>

### Side View

<p align="center">

</p>

***Features:***
* Single-channel fluorescence imaging
* Bright-field imaging
* XYZ motorized automated microscopy
* LED Matrix for quantitative imaging
* Steering fully integrated into ImSwitch

## Assembly

Certainly! The instructions you provided seem like a comprehensive guide to building a single molecule localization microscope using the modular optical system UC2. Below, I've expanded on a few aspects to ensure that the steps are clear and more detailed, providing information about some safety precautions, required materials, and additional tips.

### Microscope Building Instructions

#### 0. Introduction and Precautions

Before we begin, make sure that you are working in a well-ventilated area and wearing appropriate safety gear, such as goggles and gloves. Handling lasers requires caution, so follow the manufacturer's guidelines and take necessary safety measures.

#### Materials and Tools Needed:

- UC2 modular optical system components
- Camera with the compatible mounting system
- Achromatic lens with a suitable mount
- 3D printer (for creating mounts)
- Thorlabs 20mm tube or equivalent
- Laser with adaptable profile
- Convex lenses
- Diffuser (cling foil, etc.)
- Motor-driven translation stage
- 3D printed gears and timing belts
- Commercial XY stage
- 4-well/8-well chambers and circular 18 mm/25 mm cover glass holders
- Alignment tools, such as apertures
- LED for top-light illumination
- Various screws, bolts, and tools for assembly
- Protective gear for handling lasers and other delicate components

#### 1. Detection Layer

The camera is positioned within a cube, so that the camera chip is
centered. At a distance of 100 mm, the tube lens is positioned on the
same optical axis. As a cube is 50 mm broad, an empty cube is placed
between the camera and the lens. A 3D printed mount is combined with a
Thorlabs 20 mm tube, to which a mounted achromatic lens can be screwed
to the tube. The 3D printed mount is thick enough to not tilt while
still being movable. The 3D printed mount holding the lens is moved to
focus an object on the camera. The mirror can be placed in front of the
camera or before the tube lens. The mirror is tiltable along two axes.
The emissions from the objective are parallel. The distance can be
chosen accordingly to the build. A mirror tilted by 45 degrees reflects
the vertical emissions of the sample into the tube lens and subsequently
onto the camera.

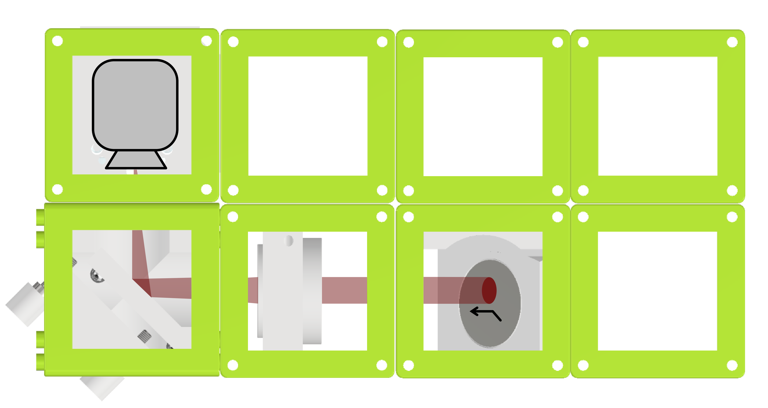
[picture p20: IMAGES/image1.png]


Emissions from the objective are reflected by the mirror, focused by the
tube lens, displaced with the tiltable mirror and imaged on the
detector.

#### 2. Laser

The laser profile can be tuned to match the application the microscope
will be used for. When imaging a Chroma red fluorescent slide, the laser
profile can be characterized. Without any modification, the laser only
illuminates a subset of the field of view. By adding a telescope build,
the laser beam is magnified. The telescope is built by placing two
convex lenses in a distance equal to the sum of their focal distances in
the light path. The magnification can then be calculated by the ratio of
the focal lengths (e.g. f1 = 3\*f2 magn. = 3x). If the beam is not
homogeneous or does not have a smooth profile or patterns that vary over
time, the beam can be homogenized through diffusing the light in the
common focal point of both telescope lenses. The diffuser can be as
simple as a cling foil, attached to a rotor or a fan motor and spinning
the foil.



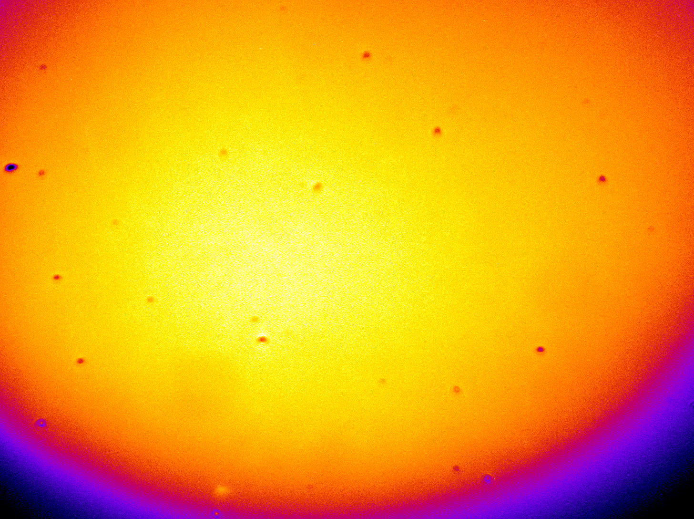
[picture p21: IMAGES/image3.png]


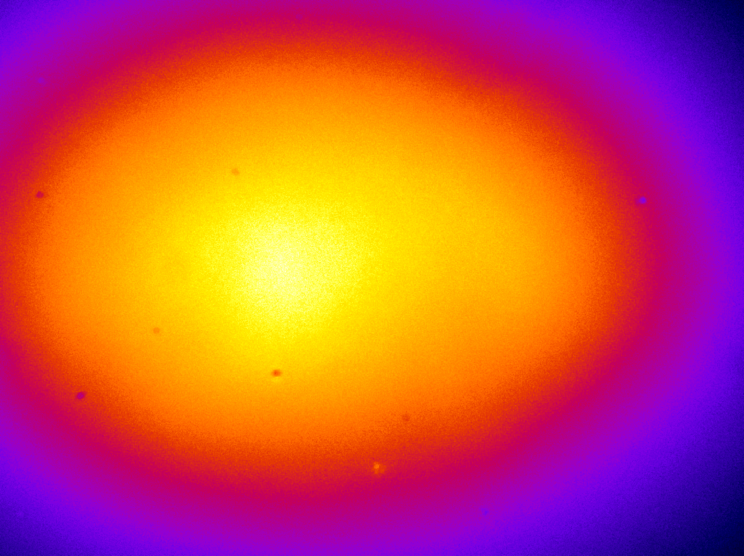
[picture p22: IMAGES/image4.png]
![](

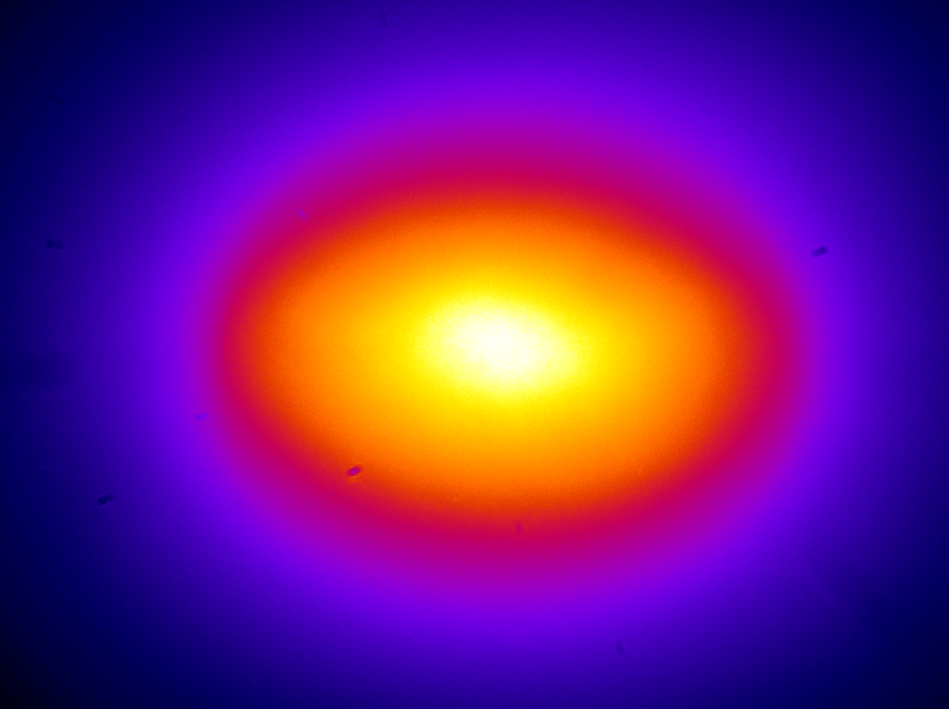
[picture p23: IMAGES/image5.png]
![](

Here, the lens l1 is focusing onto the rotating cling foil. The diffused beam is magnified by the lens l2. The
resulting beam profiles can be seen in following images:

The laser beam without magnification (left) has a smaller spot with high
laser intensity. The illumination is not homogeneous but can be
advantageous for applications needing higher laser densities. The laser
profile with a 2 times magnification (middle) and the magnification with
diffuser (right) enable homogeneous illumination of most of the field of
view.

##### Tips:

- Ensure that the diffuser is balanced properly to avoid vibrations that might affect the image quality.
- Calibration of the laser profile according to the application is crucial. Make sure to test different magnifications and diffusions.

#### 3. Excitation Layer

The laser emission can be chosen accordingly. The laser beam is then
focused by a lens into the back focal plane of the objective (here after
the filter cube in a higher vertical plane). Through a tiltable mirror,
the beam can be positioned into the center of the field of view. The
filter cube has filters adapted to the laser and the fluorophores used
in the experiments. The mount for the laser, the lens, the mirror as
well as the filter cube can all be 3D printed.

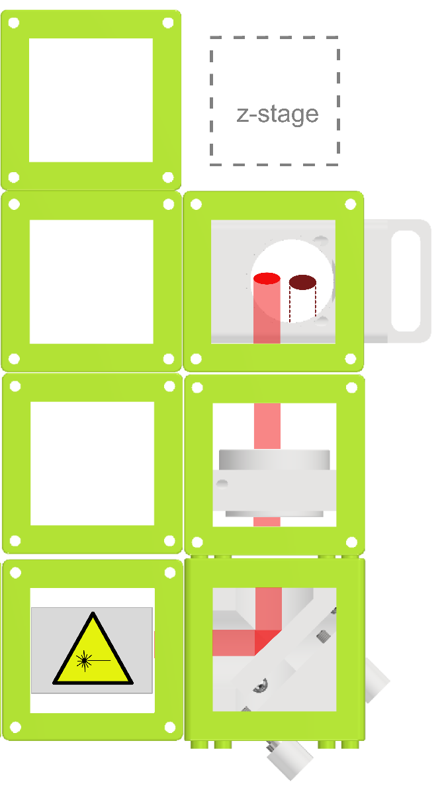
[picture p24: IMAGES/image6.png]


##### Tips:

- Ensure that all 3D printed components fit perfectly with the rest of the parts.
- The choice of filters must correspond with the laser and the fluorophores used in the experiments.

#### 4. Z Stage

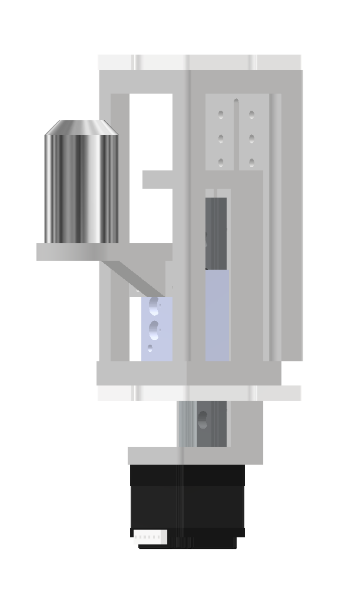
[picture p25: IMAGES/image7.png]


The z stage is a motor driven translation stage. The
stage is embedded into a 3D printed case to make the dimensions fit the
cube design. A puzzle piece on the top and in the bottom allow to build
a stable connection between the stage and the rest of the microscope. A
3D printed objective holder connects the stage to the objective. It is
advised to print the objective holder with a high percentage of infill
and a stable plastic, as the heavy objective causes strain on the
material.

##### Tips:

- Careful selection of the material for the objective holder is crucial to withstand the weight and strain.

#### 5. XY Stage

The XY stage used in the current build is a commercial solution. The
manual translation knobs were equipped with 3D printed gears. In order
to motorize the stage, motors which were also equipped with gears
transmitted the torque to the stage via timing belts. These were printed
with a softer and thus more elastic plastic. The whole stage is attached
to the rest of the microscope via a 3D printed plate, working as a
replacement for a puzzle layer, with the according perforations where
connections to the top layer of cubes was provided. Furthermore, the
stage needs a 3D printed insert, to hold the sample. Models for
4-well/8-well chambers and circular 18 mm/25 mm cover glass holders are
available. An alternative where the coverglass is directly embedded into
the 3D printed sample holder is also provided.

##### Tips:

- Calibration and testing of the XY stage should be done to ensure smooth and accurate movement.

#### 6. Alignment Procedure

To align the optics, the first step is to position all optics along the
optical axis and ensure that they are not tilted. To make this procedure
more systematic, the excitation pathway is aligned with an aperture,
which is placed between the second lens of the telescope build and the
lens focusing the laser in the back focal plane of the objective. While
imaging a fluorescent slide, an almost closed aperture is placed to
match the maximum of the laser excitation. This allows to know the
position of the laser within the sample. The emission pathway is then
adjusted to have the aperture in the center of the field of view. This
way, the maximal laser intensity spot is in the center of the field of
view, which should both theoretically be along the optical axis.

##### Tips:

- Proper alignment is essential for obtaining accurate results. Take your time and follow systematic procedures.
- Specialized alignment tools and techniques might be needed for precise adjustments.

#### 7. Top Light Illumination

The illumination for bright-field imaging needs to be spatially
invariant in relation to the objective. It is important to attach the
top-light illumination to the main body of the microscope instead of the
XY stage. This is achieved by attaching an LED to a 3D printed arm,
connected to the highest puzzle layer, thus decoupled of the possible
motions of the XY-stage.

##### Tips:

- The brightness of the LED should be adjustable to suit various imaging requirements.
- Consider using a diffuser to create more uniform illumination across the sample.

### Conclusion

Building a single molecule localization microscope with the modular optical system UC2 is an exciting and challenging project. This guide provides a step-by-step approach to construct the microscope and align its various components. Always remember to follow safety precautions and consult manufacturer's guidelines or a professional if you are unsure about any step.

Feel free to share your progress and ask questions on GitHub or other platforms, as the scientific community can be of great assistance in such projects.

Happy building!

## Bill of material

Below you will find all components necessary to build this device

### 3D printing files

All these files need to be printed. We used a Prusa i3 MK3S using PLA Prusament (Galaxy Black) at layer height 0.15 mm and infill varying between 20-40 %, depending on how much weight rests on the 3D printed part. For applications within the incubator, the use of ABS Prusament is recommended, as the thermal stability is noticeably increasing the setups stability, especially with increased working temperature and humidity. The layer height and the infill can be chosen identically for ABS as for PLA parts.

An in-depth tutorial on how to build the XY-stage can be found here https://github.com/openUC2/

An in-depth tutorial on how to build the Z-stage can be found here https://github.com/openUC2/

| Printed  | UC2 | Linear Stage mount | 00_Linear_Stage_NEMA11_Mount.ipt | 1  | $5.00 | 5 |
|---|---|---|---|----|---|-----|
| Printed  | UC2 | Linear Stage spacer | 00_Linear_Stage_NEMA11_Mount_Lid.ipt | 1  | $1.00 | 1 |
| IM | openUC2 | UC2 Puzzle piece | 10_Base_puzzle_v3.ipt | 26 | $5.00 | 130 |
| Printed  | UC2 | UC2 objective Mount linear stage | 20_Cube_Insert_Cube_Z-Stage_NEMA11_china_objectivemount_v3.ipt | 1  | $1.00 | 1 |
| IM | openUC2 | openUC2 IM Cube | 10_Cube_1x1_IM.ipt | 42 | $5.00 | 210 |
| External | | 5 mm Neodym Magnets | 00_BallMagnets_5mm_single.ipt | 9  | | 0 |
| Printed  | UC2 | UC2 Insert for Kinematic Mirror Part1 | 20_Cube_Insert_Kinematic_Mirrormount_45_base_part1.ipt | 3  | $5.00 | 15  |
| Printed  | UC2 | UC2 Insert for Kinematic Mirror Part2 | 20_Cube_Insert_Kinematic_Mirrormount_45_base_part2.ipt | 3  | $1.00 | 3 |
| Printed  | UC2 | Adapter for Nut | 30_Adapter_M3_nut.ipt | 9  | $1.00 | 9 |
| External | Würth | DIN 912 - M3 x 0.5 x 12 x 10.75.ipt | DIN 912 - M3 x 0.5 x 12 x 10.75.ipt | 15 | $1.00 | 15  |
| Printed  | UC2 | UC2 Insert for 1 inch Mirror, 45° | 20_Cube_Insert_Kinematic_Mirrormount_45_Thorlabsadapter.ipt | 3  | $5.00 | 15  |
| External | Thorlabs | Thorlabs PF 10-03-P01 | 00_Thorlabs_PF10-03-P01-Step.ipt | 3  | $25.00  | 75  |
| External | | Allied Vision Alvium USB 3.1 Kamera 1800 U-158m, 1/2,9", 1,58 MP, C-Mount, monochrom | *Varies* | 2  | $445.00 | 890 |
| External | | C:\cad\PSP2011Client\Work\139705407318IP01941702.stp | 00_Basler_ace_USB3_C-Mount.ipt | 1  | | 0 |
| | UC2 | | 20_Cube_Insert_Cmount_v3.ipt | 1  | $5.00 | 5 |
| External | Thorlabs | Thorlabs CP33 | 00_Thorlabs_Cage_CP33_M.ipt | 2  | $20.00  | 40  |
| Printed  | UC2 | UC2 Insert for Thorlabs Cage | 20_Cube_Insert_Thorlabs_Pins.ipt | 2  | $5.00 | 10  |
| Printed  | UC2 | UC2 Insert for Thorlabs 1inch lens | 20_Cube_Insert_Thorlabs_SM1Tube.ipt | 2  | $5.00 | 10  |
| | Thorlabs | Thorlabs AC254-050-A-ML | 00_THORLABS_AC254-050-A-ML-Step.ipt | 2  | $100.00 | 200 |
| Printed  | UC2 | Filtermount | 30_Cube_Insert_Filter_Revolver_Filter_base_single_v3.ipt | 1  | $5.00 | 5 |
| External | Euromex | Euromex Mechanischer 180 x 155 mm Objekttisch mit integriertem 75 x 55 mm X-Y-Kreuztisch und transparenter Glasplatte, NZ.9505 | 00_XYTable_china_75_55mm.ipt | 1  | $200.00 | 200 |
| Printed  | | Uc2 Insert for Allied Vision Camera | 30_XYTabel_Aliexpress_basplateadapter.ipt | 1  | $7.00 | 7 |
| Printed  | | Motormount for XY stge | 30_XYTable_Aliexpress_motormount.ipt | 1  | $7.00 | 7 |
| Printed  | | Sample Inset for XY Stage | 30_XYTable_Aliexpress_sampleinsert_round.ipt | 1  | $7.00 | 7 |
| External | Roboter Bausatz | GT2 Riemenscheibe 16 Zähne 4mm Bohrung für 6mm Zahnriemen | 00_XYTable_pulley.ipt | 2  | $2.00 | 4 |
| Printed  | UC2 | Timing Gear Small | 00_XYTable_medium_gear.ipt | 1  | $2.00 | 2 |
| | UC2 | Timing Gear Large | 00_XYTable_large_gear.ipt | 1  | $2.00 | 2 |
| Printed  | UC2 | Printed Timing Belt Long | 00_GT2_TimingBelt_flexible_Modular_xytable_large_89tooth.ipt | 1  | $5.00 | 5 |
| Printed  | UC2 | Printed Timing Belt Short | 00_GT2_TimingBelt_flexible_Modular_xytable_large_65tooth.ipt | 1  | $5.00 | 5 |
| External | Laserlands.net  | 638nm Red Laser Module 500mW Round Dot Focusable TTL 3050 | 00_LASER_640nm.ipt | 1  | $40.00  | 40  |
| Printed  | UC2 | holder for LED Array | 40_Cube_XY_Table_Illumination_Arm.ipt | 1  | $5.00 | 5 |
| External | Adafruit | Adafruit 64 LED array (8x8) | 00_LED-ARRAY.ipt | 1  | $20.00  | 20  |
| External | Chroma | Chroma ET655 | 00_Chroma_ET655lp long-pass.ipt | 1  | $250.00 | 250 |
| External | Chroma | Chroma ZET 636 | 00_Chroma ZET635_Excitationfilter.ipt | 1  | $250.00 | 250 |
| External | Chroma | Chroma ZT640 | 00_Chroma_ZT640rdc.ipt | 1  | $250.00 | 250 |
| External | - | Linear Stage 50mm , Nema 12, MGN9h | | 1  | 50 | 50  |

### Design files

The original design files are in the [INVENTOR](./INVENTOR) folder.

## Showcase
The compact size of the setup and the modular character allow to adapt the setup to any incubator. ImSwitch can be started from any given compute ror laptop. Simple USB cables connect the microscope to the outside (computer) for full control over its functionalities.
Here you can see the device in action:

<p align="center">

</p>gith

<p align="center">

</p>

<p align="center">

</p>

<p align="center">

</p>

<p align="center">

</p>

<p align="center">

</p>

## Wide-field imaging

## Mechanical stability of the setup

## Live-cell imaging

## Single molecule applications

## Get Involved

This project is open so that anyone can get involved. You don't even have to learn CAD designing or programming. Find ways you can contribute in  [CONTRIBUTING](https://github.com/openUC2/UC2-GIT/blob/master/CONTRIBUTING.md)

## License and Collaboration

This project is open-source and is released under the CERN open hardware license. Our aim is to make the kits commercially available.
We encourage everyone who is using our Toolbox to share their results and ideas, so that the Toolbox keeps improving. It should serve as a easy-to-use and easy-to-access general purpose building block solution for the area of STEAM education. All the design files are generally for free, but we would like to hear from you how is it going.

You're free to fork the project and enhance it. If you have any suggestions to improve it or add any additional functions make a pull-request or file an issue.

Please find the type of licenses [here](https://github.com/openUC2/UC2-GIT/blob/master/License.md)

REMARK: All files have been designed using Autodesk Inventor 2019 (EDUCATION)

## Collaborating
If you find this project useful, please like this repository, follow us on Twitter and cite the webpage! :-)

# Unsorted Images


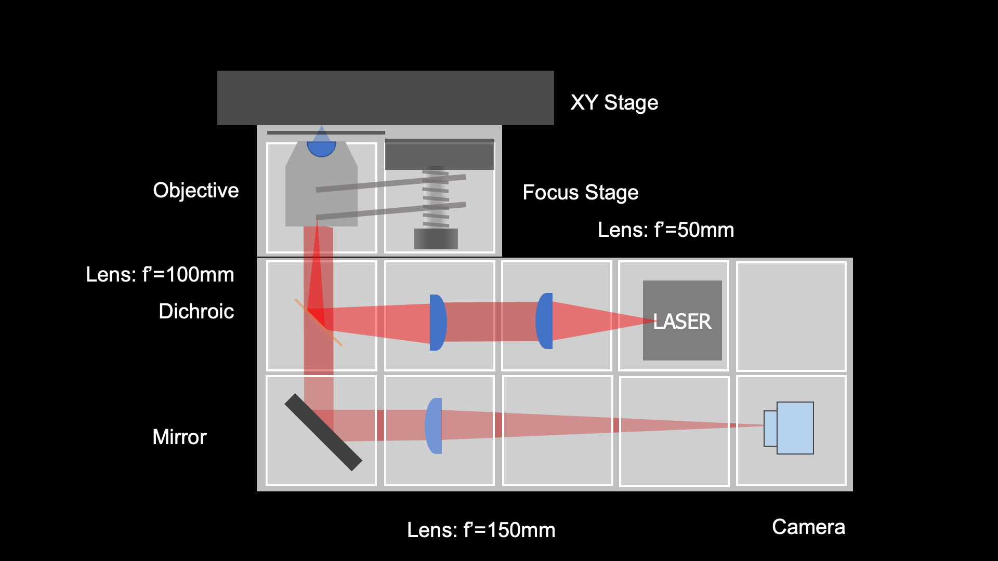
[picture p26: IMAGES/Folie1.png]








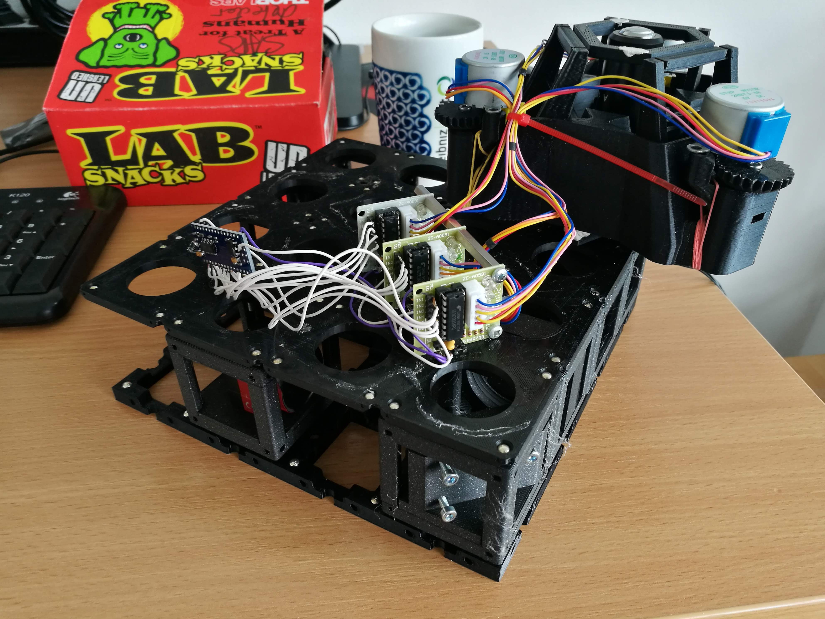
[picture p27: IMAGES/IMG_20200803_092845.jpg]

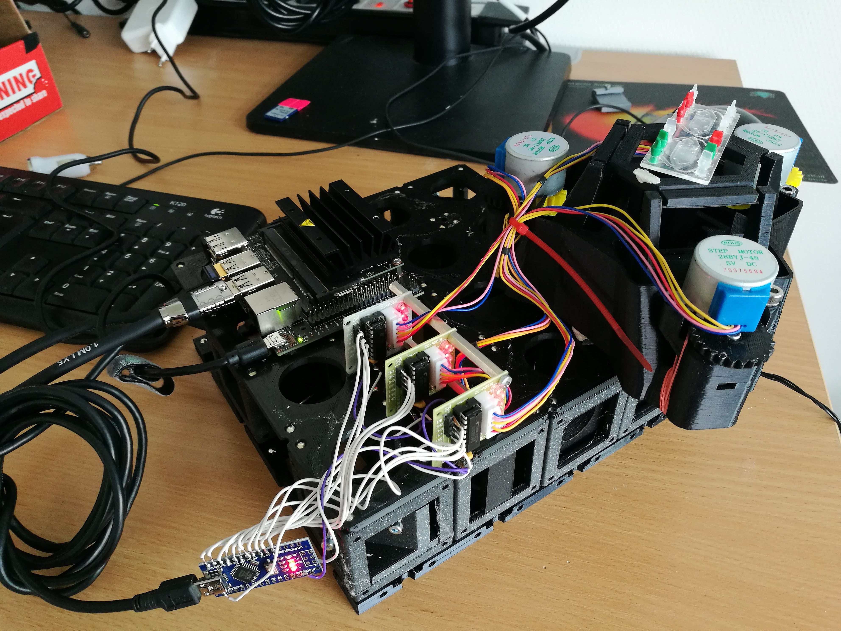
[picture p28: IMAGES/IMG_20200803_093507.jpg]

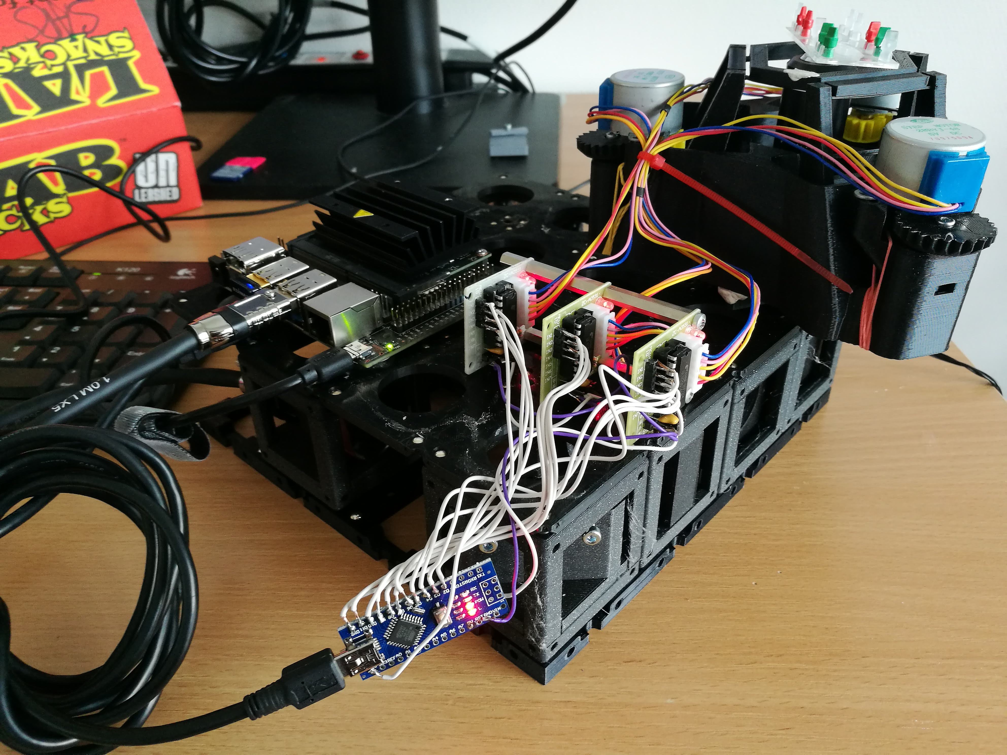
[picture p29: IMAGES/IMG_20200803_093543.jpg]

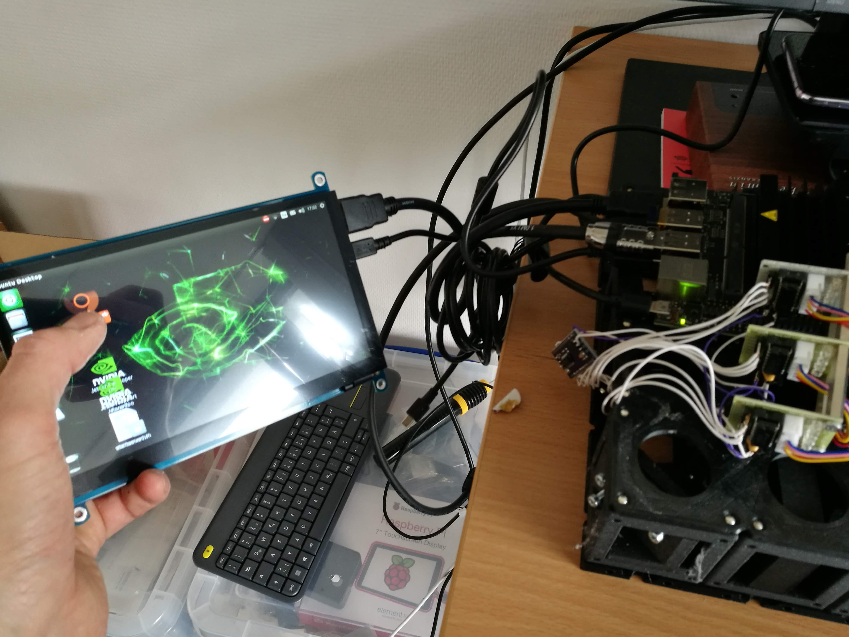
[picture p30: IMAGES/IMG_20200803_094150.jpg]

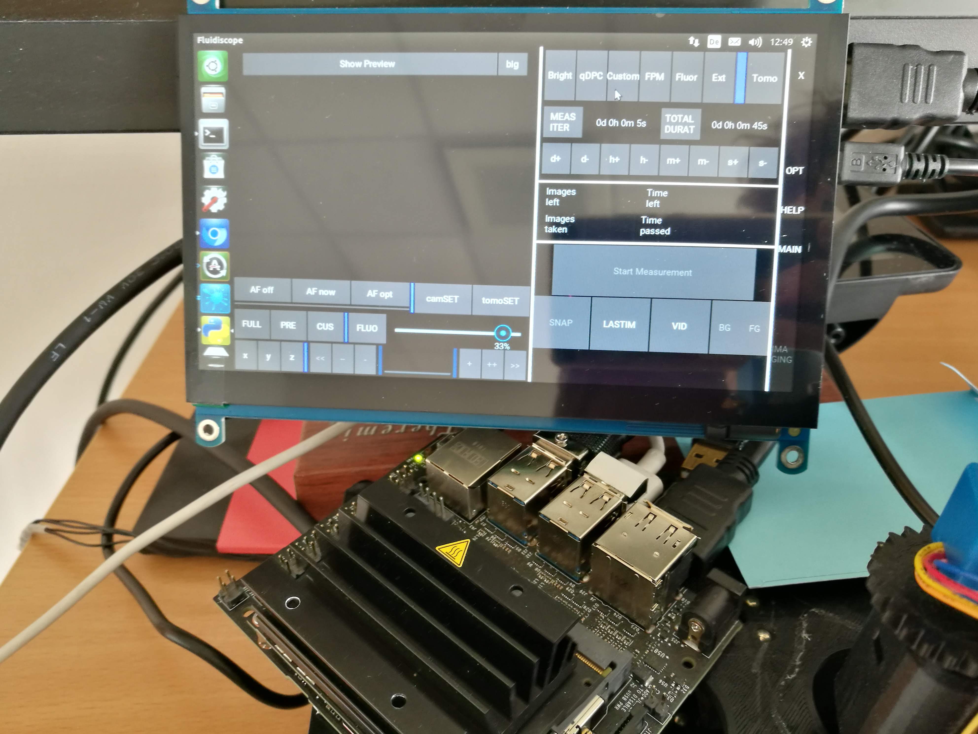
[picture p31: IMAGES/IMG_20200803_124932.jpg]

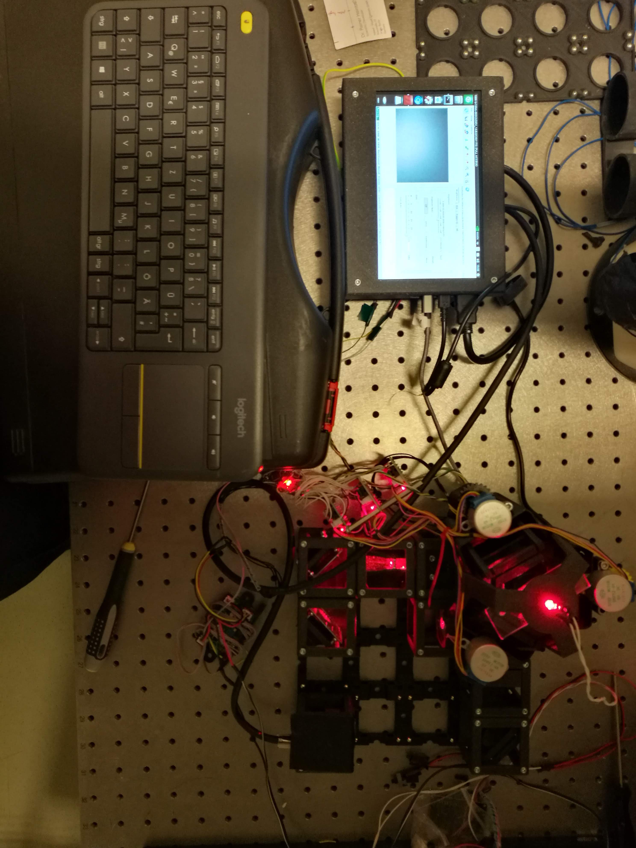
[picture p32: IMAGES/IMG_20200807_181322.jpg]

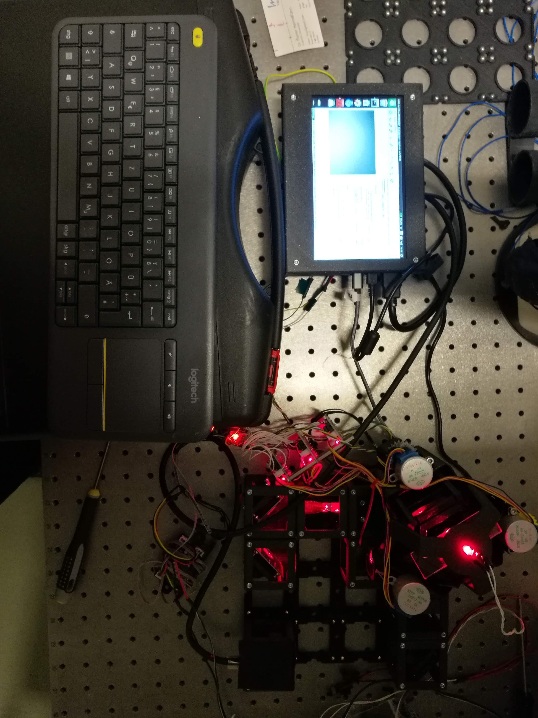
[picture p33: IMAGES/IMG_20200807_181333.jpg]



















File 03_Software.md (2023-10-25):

# Software

For the control and acquisition software, we use ImSwitch. This is an open-source software centered around Napari as a multi-layer viewer and a rich framework for QT-based widgets. We make use of the open-source localization framework "microEye" ()

## Installation

For the installation we advise you to have a look at the ImSwitch repository here https://github.com/kasasxav/ImSwitch/

After setting up ImSwitch, you can enable STORM reconstruction in real time using the MicroEye Plugin by adding the following configuration to the ImSwitch config file that is located in `~/Documents/ImSwitchConfig/config/imcontrol_options.json`

```json
{
    "setupFileName": "example_uc2_storm_alliedvision.json",
    "recording": {
        "outputFolder": "./ImSwitch/ImSwitch/recordings",
        "includeDateInOutputFolder": true
    },
    "watcher": {
        "outputFolder": "/Users/bene/ImSwitchConfig/scripts"
    }
}
```

The setup file with the actual hardware configuration can be placed here:

`~/Documents/ImSwitchConfig/imcontrol_setups/example_uc2_storm_alliedvision.json`

```json
{
  "positioners": {
    "ESP32Stage": {
      "managerName": "ESP32StageManager",
      "managerProperties": {
        "rs232device": "ESP32"
      },
      "axes": [
        "X",
        "Y",
        "Z"
      ],
      "forScanning": true,
      "forPositioning": true
    }
  },
  "rs232devices": {
    "ESP32": {
      "managerName": "ESP32Manager",
      "managerProperties": {
        "host_": "192.168.43.129",
        "serialport_windows": "COM5",
        "serialport": "/dev/cu./dev/cu.SLAB_USBtoUART"
      }
    }
  },
  "lasers": {
    "488 Laser": {
      "analogChannel": null,
      "digitalLine": null,
      "managerName": "ESP32LEDLaserManager",
      "managerProperties": {
        "rs232device": "ESP32",
        "channel_index": 1,
        "filter_change": false,
        "laser_despeckle_period": 10,
        "laser_despeckle_amplitude": 0
      },
      "wavelength": 488,
      "valueRangeMin": 0,
      "valueRangeMax": 1024
    },
    "635 Laser": {
      "analogChannel": null,
      "digitalLine": null,
      "managerName": "ESP32LEDLaserManager",
      "managerProperties": {
        "rs232device": "ESP32",
        "channel_index": 2,
        "filter_change": false,
        "laser_despeckle_period": 10,
        "laser_despeckle_amplitude": 0
      },
      "wavelength": 635,
      "valueRangeMin": 0,
      "valueRangeMax": 1024
    },
    "LED": {
      "analogChannel": null,
      "digitalLine": null,
      "managerName": "ESP32LEDLaserManager",
      "managerProperties": {
        "rs232device": "ESP32",
        "channel_index": "LED",
        "filter_change": false,
        "filter_axis": 3,
        "filter_position": 32000,
        "filter_position_init": -0
      },
      "wavelength": 635,
      "valueRangeMin": 0,
      "valueRangeMax": 255
    }
  },
  "detectors": {
    "WidefieldCamera": {
        "analogChannel": null,
        "digitalLine": null,
        "managerName": "AVManager",
        "managerProperties": {
            "cameraListIndex": 1,
            "mocktype": "STORM",
            "mockstackpath": "/Users/bene/Downloads/New_SMLM_datasets/ROI_cos7MT_AF647fluopaint.tif",
            "avcam": {
                "exposure": 0,
                "gain": 0,
                "blacklevel": 100,
                "image_width": 1000,
                "image_height": 1000,
                "pixel_format": "Mono12"
            }
        },
        "forAcquisition": true,
        "forFocusLock": false
    }
},
"rois": {
    "Full chip": {
      "x": 600,
      "y": 600,
      "w": 1200,
      "h": 1200
    }
  },
  "LEDMatrixs": {
    "ESP32 LEDMatrix": {
      "analogChannel": null,
      "digitalLine": null,
      "managerName": "ESP32LEDMatrixManager",
      "managerProperties": {
        "rs232device": "ESP32",
        "Nx": 4,
        "Ny": 4
      },
      "wavelength": 488,
      "valueRangeMin": 0,
      "valueRangeMax": 32768
    }
  },
  "autofocus": {
    "camera": "WidefieldCamera",
    "positioner": "ESP32Stage",
    "updateFreq": 10,
    "frameCropx": 780,
    "frameCropy": 400,
    "frameCropw": 500,
    "frameCroph": 100
  },
  "availableWidgets": [
    "Settings",
    "View",
    "Recording",
    "Image",
    "Laser",
    "Positioner",
    "Autofocus",
    "STORMRecon"
  ]
}
```

## ImSwitch in Action

Here you can find a tour on Youtube how to set up everything and what it can do.

<p align="center">

</p>

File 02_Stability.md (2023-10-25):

## Setup stability



Measurement of the drift of fluorescent TS beads on the UC2 setup with
60x objective over a duration of two hours positioned upon **a.** an
optical table **b.** a common laboratory bench. Bead positions are
estimated through localization and displacement in **i.** and **ii.**
are plotted in the graphs below. **c.** (for the optical table **i.**)
and **d.** (for the laboratory bench **i.**) show the variation in the
sigma value of the localized beads over the measurement duration. The
sigma value correlates with the defocusing of the beads i.e. low changes
in sigma suggest small fluctuations of the samples axial position.

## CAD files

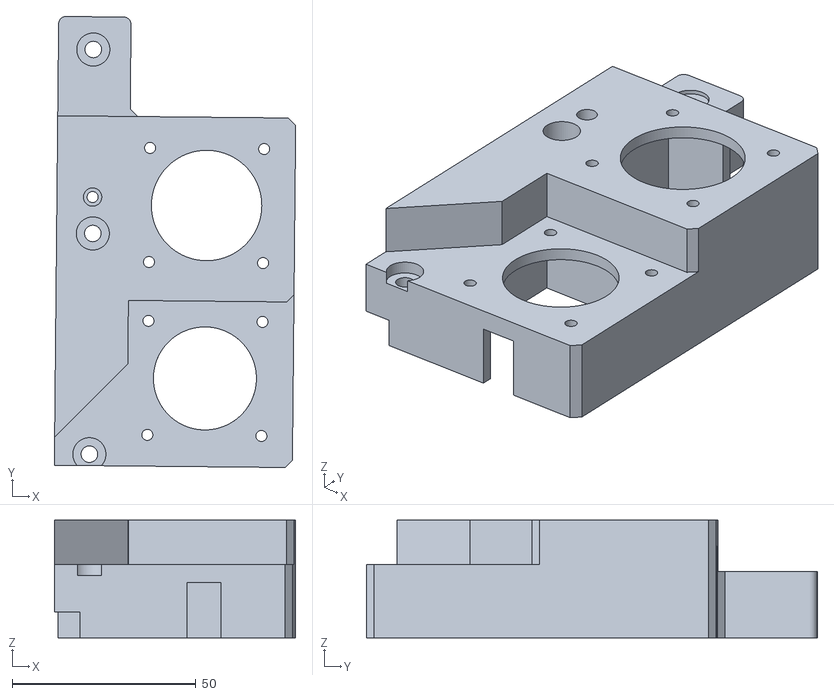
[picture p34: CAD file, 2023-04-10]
STL/Application_Fluorescence_Microscope_Infinity_Inverted_STORM_v3_30_XYTable_Aliexpress_motormount_126.stl
65.6 x 122.6 x 32.0

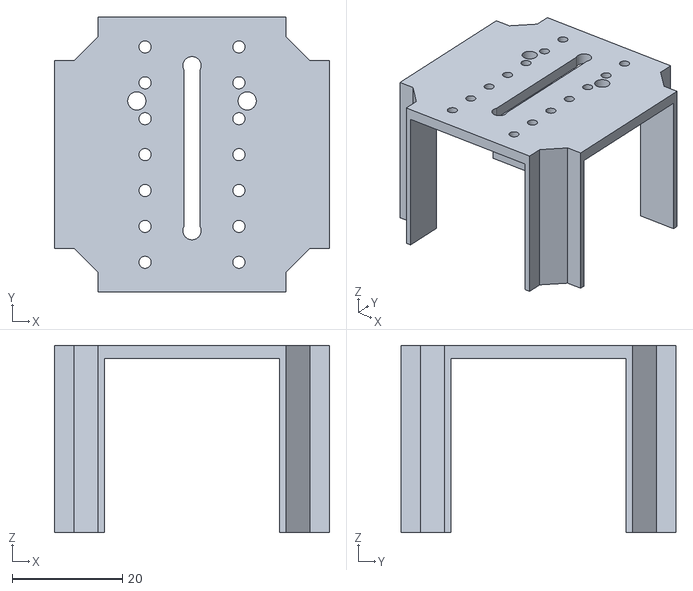
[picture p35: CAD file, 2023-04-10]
STL/Application_Fluorescence_Microscope_Infinity_Inverted_STORM_v3_20_Cube_insert_AlliedVision_Alvium_v3_32.stl
49.8 x 49.8 x 33.9

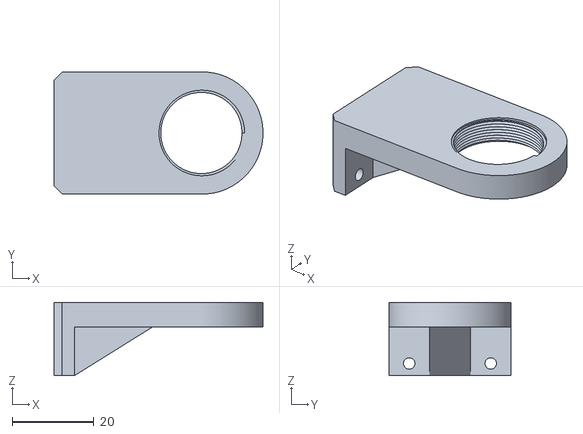
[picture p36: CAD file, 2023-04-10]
STL/Application_Fluorescence_Microscope_Infinity_Inverted_STORM_v3_20_Cube_Insert_Cube_Z-Stage_NEMA11_china_objectivemount_v3_10.stl
51.3 x 30.0 x 18.0

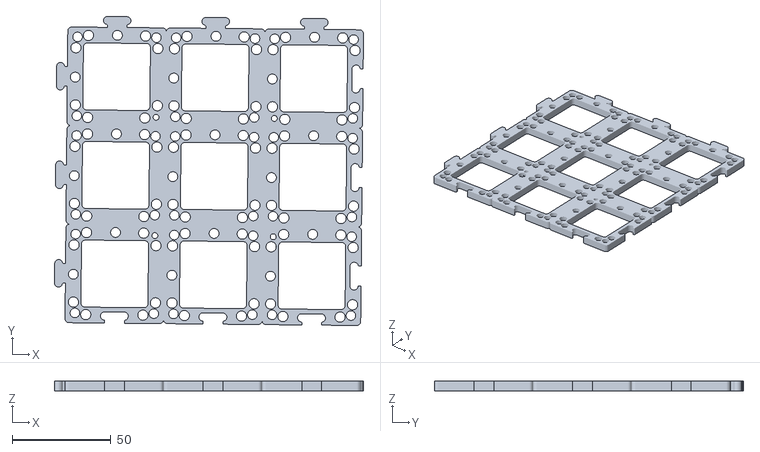
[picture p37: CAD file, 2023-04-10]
STL/Application_Fluorescence_Microscope_Infinity_Inverted_STORM_v3_30_XYTabel_Aliexpress_basplateadapter_125.stl
156.7 x 156.7 x 5.00

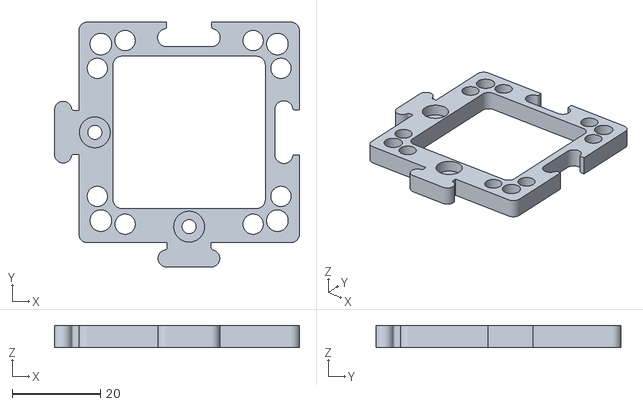
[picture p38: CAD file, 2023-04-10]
STL/Application_Fluorescence_Microscope_Infinity_Inverted_STORM_v3_10_Base_puzzle_v3_8.stl
55.5 x 55.5 x 5.00

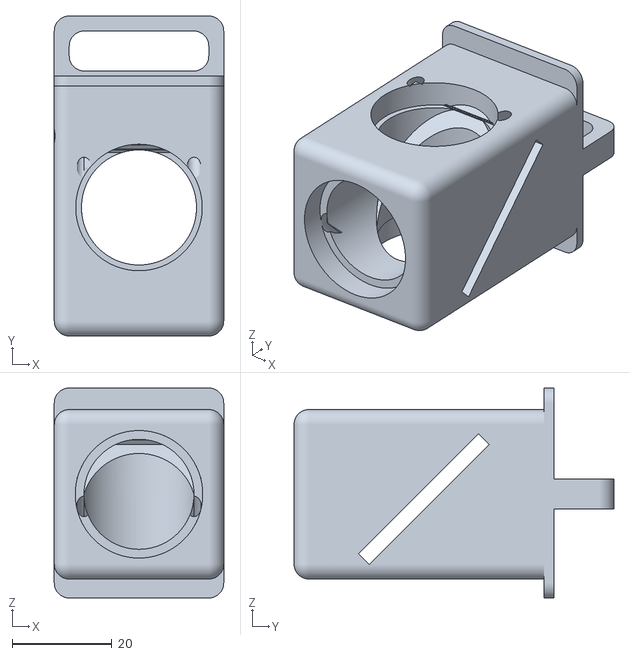
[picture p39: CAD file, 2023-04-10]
STL/Application_Fluorescence_Microscope_Infinity_Inverted_STORM_v3_30_Cube_Insert_Filter_Revolver_Filter_base_single_v3_119.stl
33.9 x 64.0 x 42.0

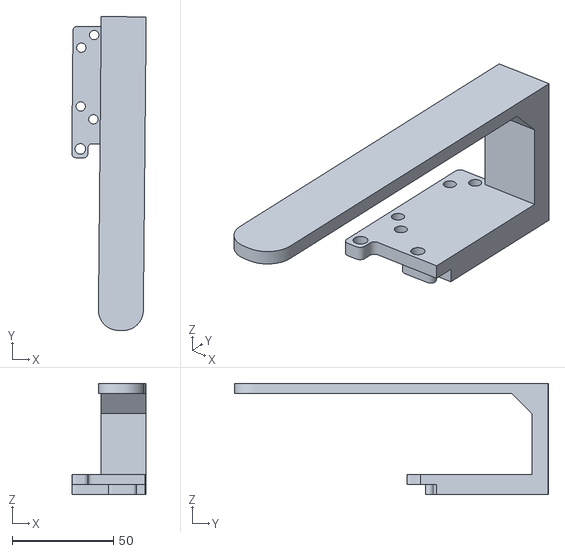
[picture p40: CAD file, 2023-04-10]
STL/Application_Fluorescence_Microscope_Infinity_Inverted_STORM_v3_40_Cube_XY_Table_Illumination_Arm_164.stl
36.8 x 155.1 x 55.0

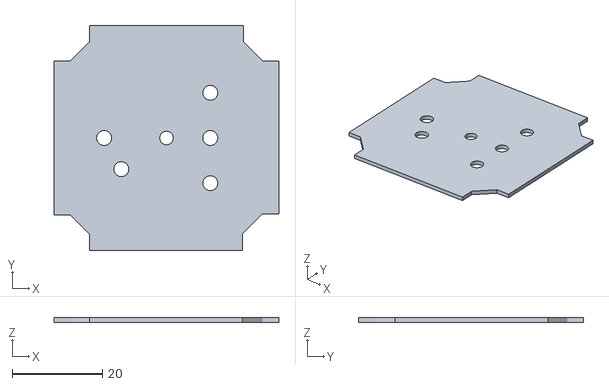
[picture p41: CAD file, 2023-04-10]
STL/Application_Fluorescence_Microscope_Infinity_Inverted_STORM_v3_20_Cube_insert_Laser_Block_adjustable_v3_162.stl
49.8 x 49.8 x 1.00

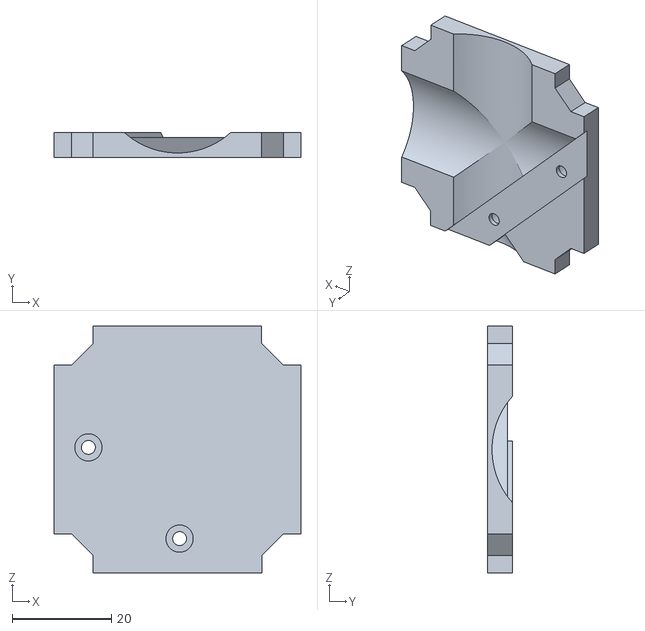
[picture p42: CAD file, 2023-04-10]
STL/Application_Fluorescence_Microscope_Infinity_Inverted_STORM_v3_20_Cube_Insert_Kinematic_Mirrormount_45_base_part1_13.stl
49.8 x 5.00 x 49.8

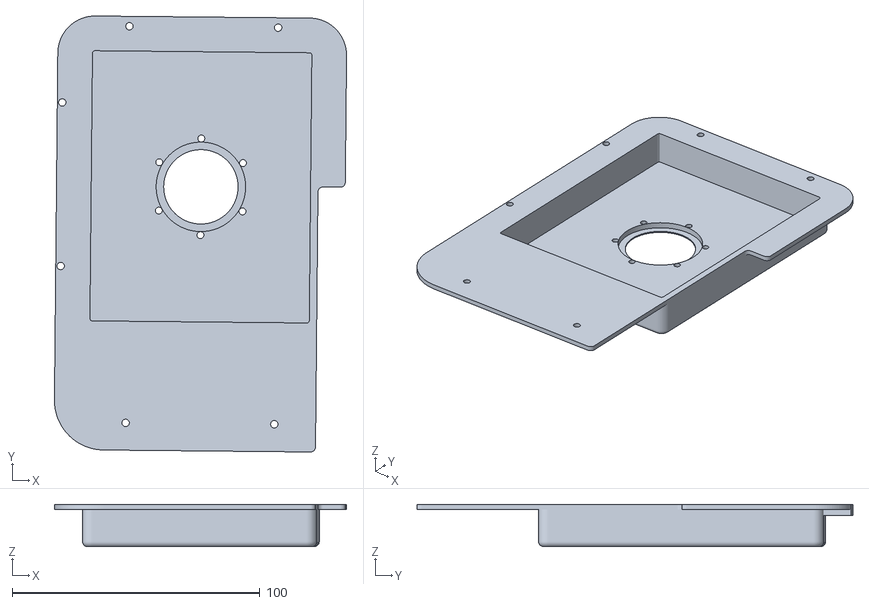
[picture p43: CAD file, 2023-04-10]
STL/Application_Fluorescence_Microscope_Infinity_Inverted_STORM_v3_30_XYTable_Aliexpress_sampleinsert_round_127.stl
117.8 x 175.9 x 17.0

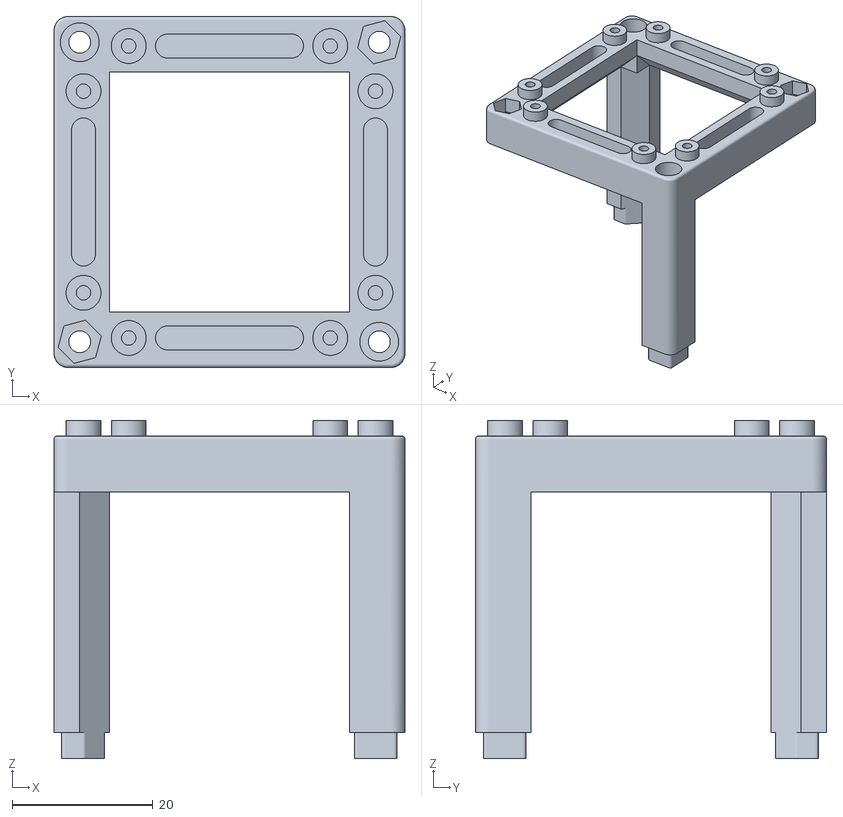
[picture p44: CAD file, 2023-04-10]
STL/Application_Fluorescence_Microscope_Infinity_Inverted_STORM_v3_10_Cube_1x1_IM_11.stl
49.8 x 49.8 x 48.0

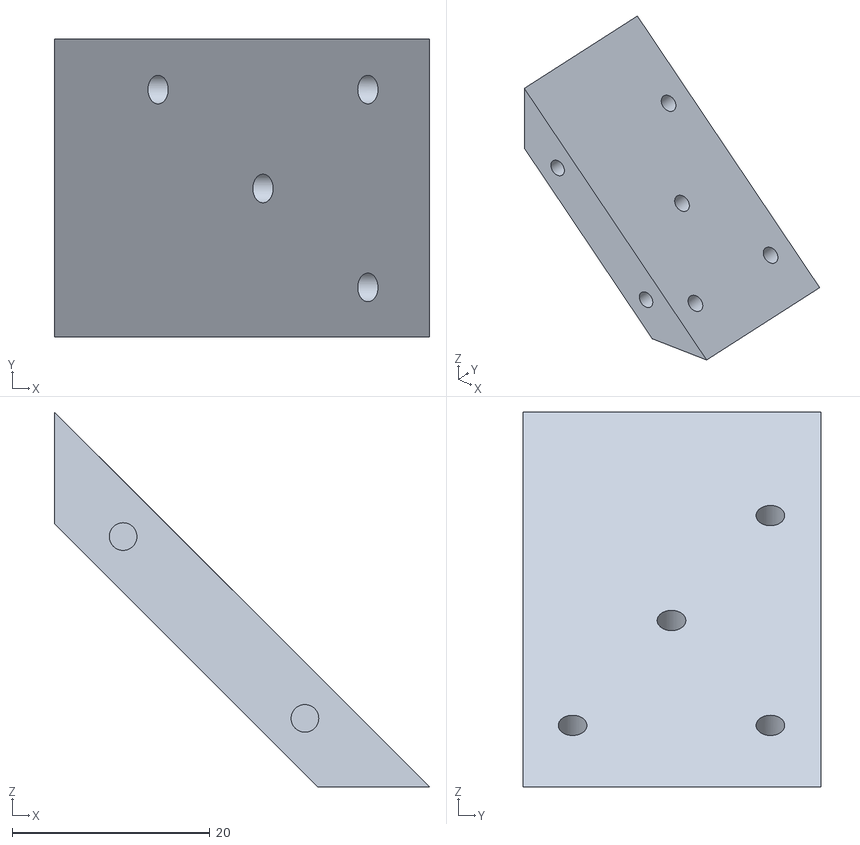
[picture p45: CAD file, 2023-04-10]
STL/Application_Fluorescence_Microscope_Infinity_Inverted_STORM_v3_20_Cube_Insert_Kinematic_Mirrormount_45_base_part2_14.stl
37.9 x 30.1 x 37.9

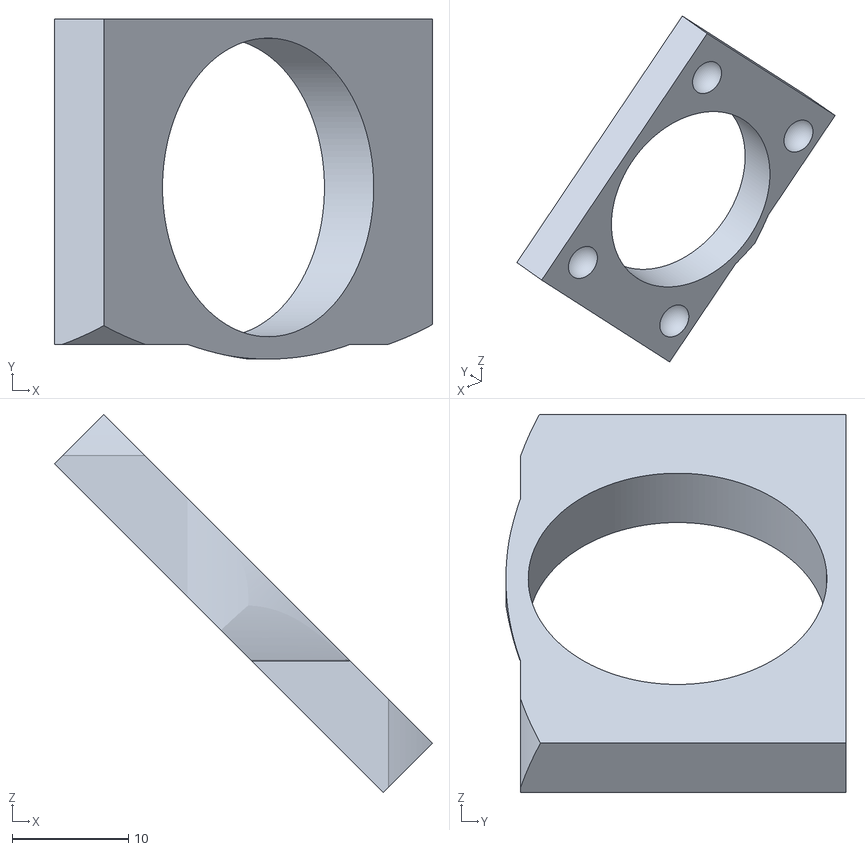
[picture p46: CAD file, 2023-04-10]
STL/Application_Fluorescence_Microscope_Infinity_Inverted_STORM_v3_20_Cube_Insert_Kinematic_Mirrormount_45_Thorlabsadapter_24.stl
32.5 x 29.3 x 32.5

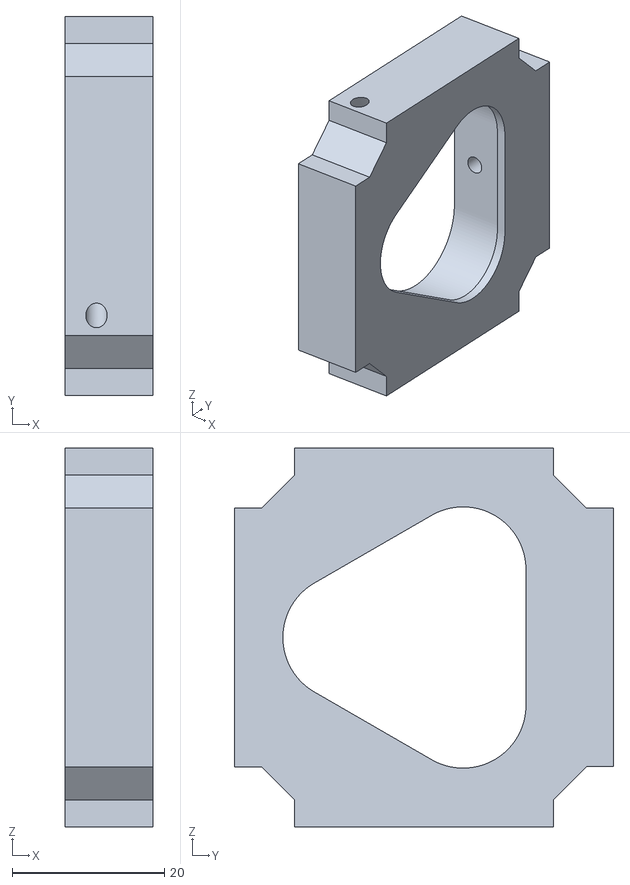
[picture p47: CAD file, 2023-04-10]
STL/Application_Fluorescence_Microscope_Infinity_Inverted_STORM_v3_20_Cube_Insert_Thorlabs_SM1Tube_117.stl
11.5 x 49.8 x 49.8

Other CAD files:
STL/Application_Fluorescence_Microscope_Infinity_Inverted_STORM_v3_10_Base_puzzle_v3_9.stl
INVENTOR/00_0-ring.ipt
INVENTOR/00_Arduino_CNC_Assembly.iam
INVENTOR/00_BallMagnets_5mm_single.ipt
INVENTOR/00_Basler_ace_USB3_C-Mount.ipt
INVENTOR/00_Carriage.ipt
INVENTOR/00_Coverglass_25mm.ipt
INVENTOR/00_Filter_25mm.ipt
INVENTOR/00_GT2_TimingBelt_flexible_Modular_xytable_large_65tooth.ipt
INVENTOR/00_GT2_TimingBelt_flexible_Modular_xytable_large_89tooth.ipt
INVENTOR/00_LASER_640nm.ipt
INVENTOR/00_LED-ARRAY.ipt
INVENTOR/00_Linear_Stage_NEMA11_Mount.ipt
INVENTOR/00_Linear_Stage_NEMA11_Mount_Lid.ipt
INVENTOR/00_Linear_Stage_NEMA11_china.iam
INVENTOR/00_NEMA11_spindle.ipt
INVENTOR/00_NEMA17_pancake.iam
INVENTOR/00_THORLABS_AC254-050-A-ML-Step.ipt
INVENTOR/00_Thorlabs_Cage_CP33_M.ipt
INVENTOR/00_Thorlabs_PF10-03-P01-Step.ipt
INVENTOR/00_XYTable_china_75_55mm.ipt
INVENTOR/00_XYTable_large_gear.ipt
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

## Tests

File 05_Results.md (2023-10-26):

## Imaging with the UC2-STORM setup

# Widefield imaging with the UC2 setup

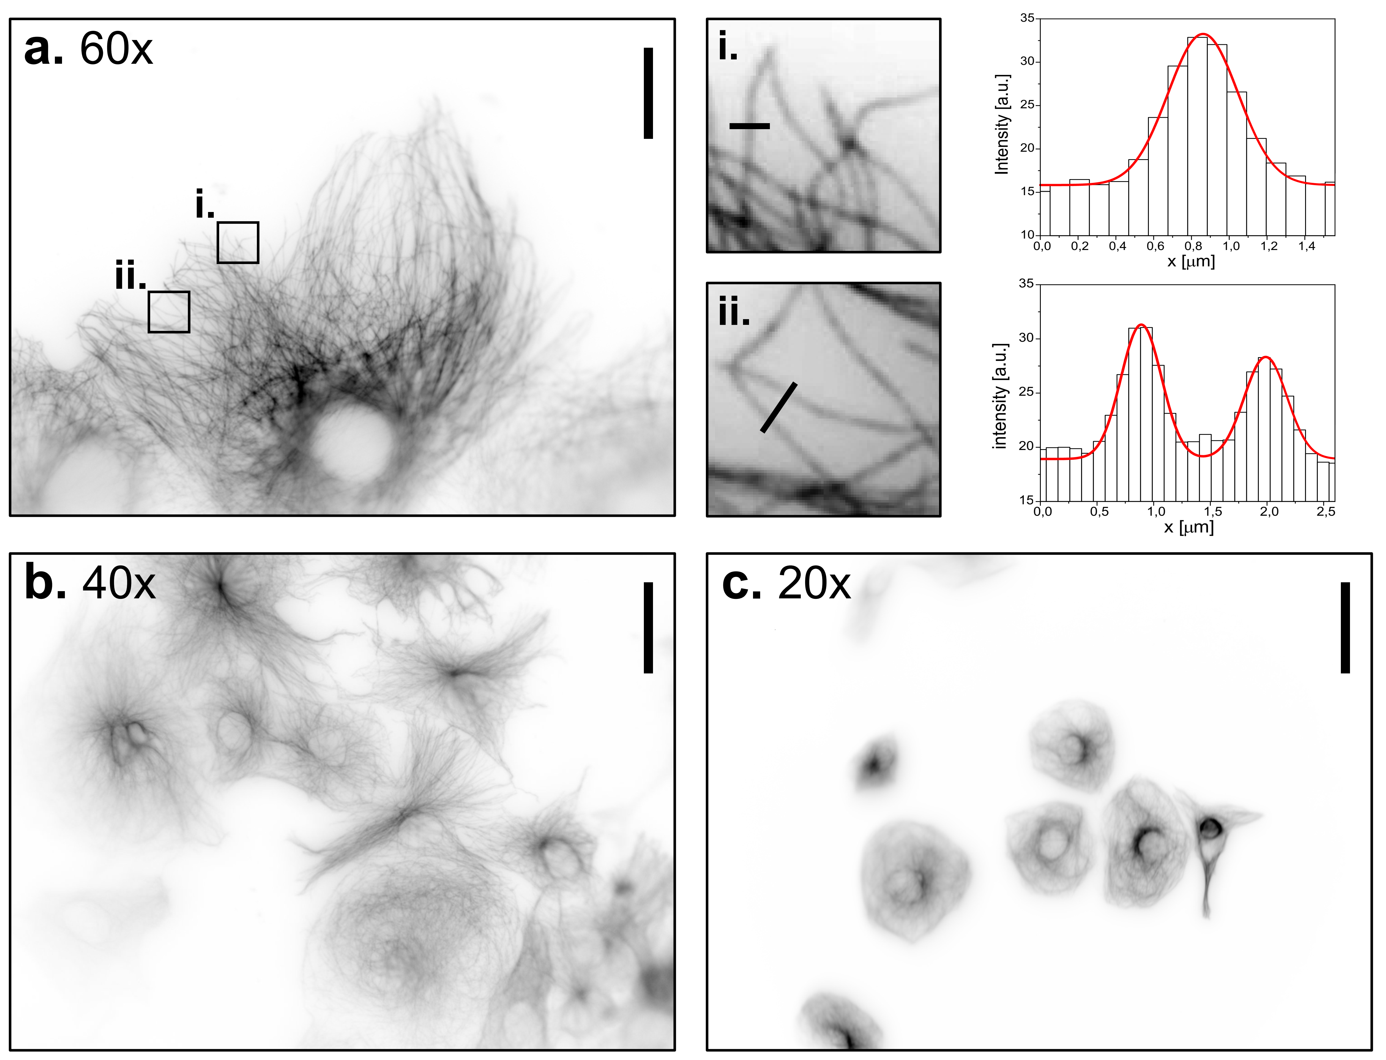
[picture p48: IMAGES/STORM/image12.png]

Widefield images of CV-1 cells immune-stained against tubulin, at
different magnifications using the UC2 microscope. **a.** 60x objective,
scale bar represents 30 µm. Two regions of interest have been zoomed in
to demonstrate the ability to detect and characterize single
microtubules. **b.** 40x objective, scale bar represents 45 µm. **c.**
20x objective, scale bar represents 90 µm.

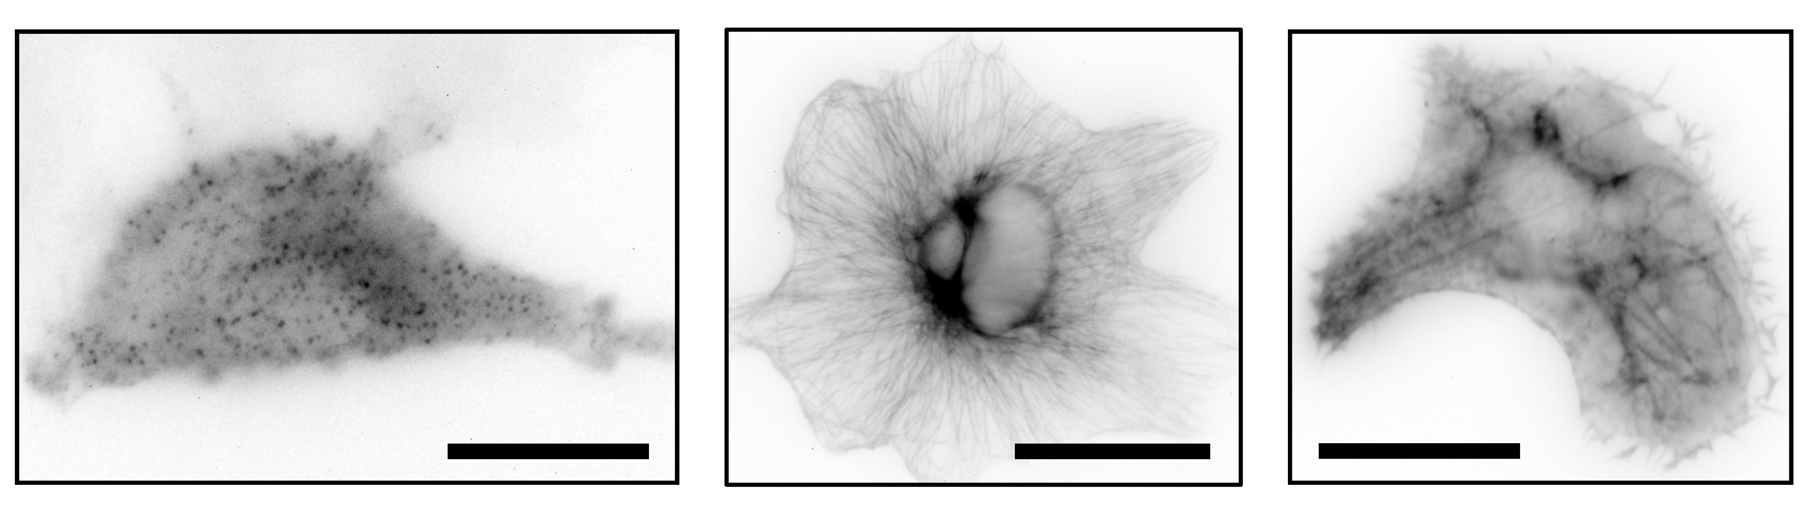
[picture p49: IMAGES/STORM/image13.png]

Widefield images of immune-stained clathrin coated pits (left),
immune-stained tubulin (middle) and SiR Actin stain of CV-1 cells with
the UC2 setup and a 60x objective. Scale bar represents 25 µm.

# Live-cell imaging at room temperature


Live cell imaging of CV-1 cells stained with SiR actin over a period of
five hours.

# Live-cell imaging at within the incubator

<p align="center">

</p>gith
Microscope is placed within the incubator for continuous imaging in the fluorescent as well as top-light channel. Some incubators have a special passage for cables. In this case, the cables were just led on the rubber guard band on the edge of the incubator. To minimize the disturbance through the cables and help the incubator be more air-tight, the cables can be replaced by flat-cables.


Live cell imaging of T98G cells stained with SYTO far red nucleic dye
over a period of two days within an incubator.

# Single molecule application: Single Particle Tracking 

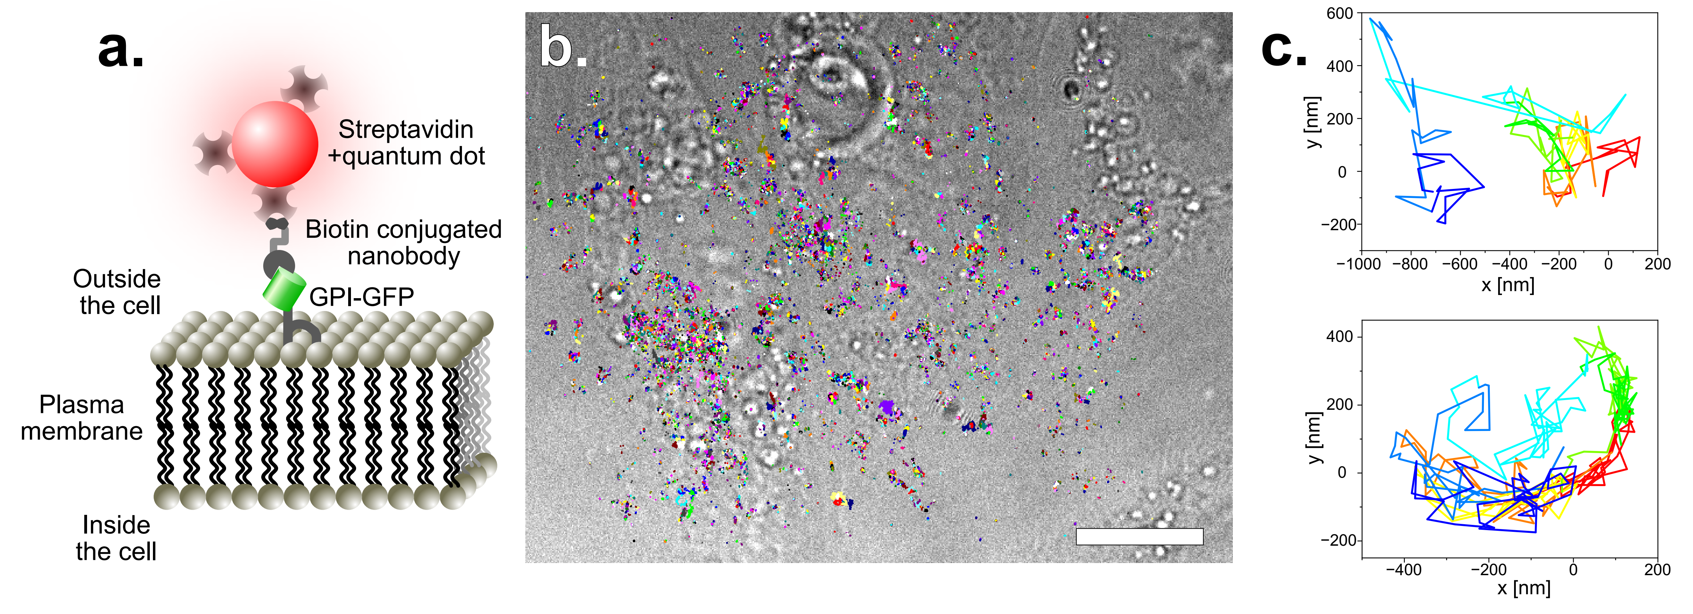
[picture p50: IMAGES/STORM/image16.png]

Single particle tracking of GPI-GFP on HeLa cells. For more
photostability, the tracks are acquired by imaging quantum dots. These
have been functionalized with straptavidin and are attached to GFP via
biotin conjugated anti-GFP nanobodies. The construct is schematically
disaplayed in **a.** The acquired tracks are overlayed on a bright-field
image of the HeLa cells (**b.**) (scale bar represents 10 µm). Two
single tracks are exeplarily displayed in **c.**

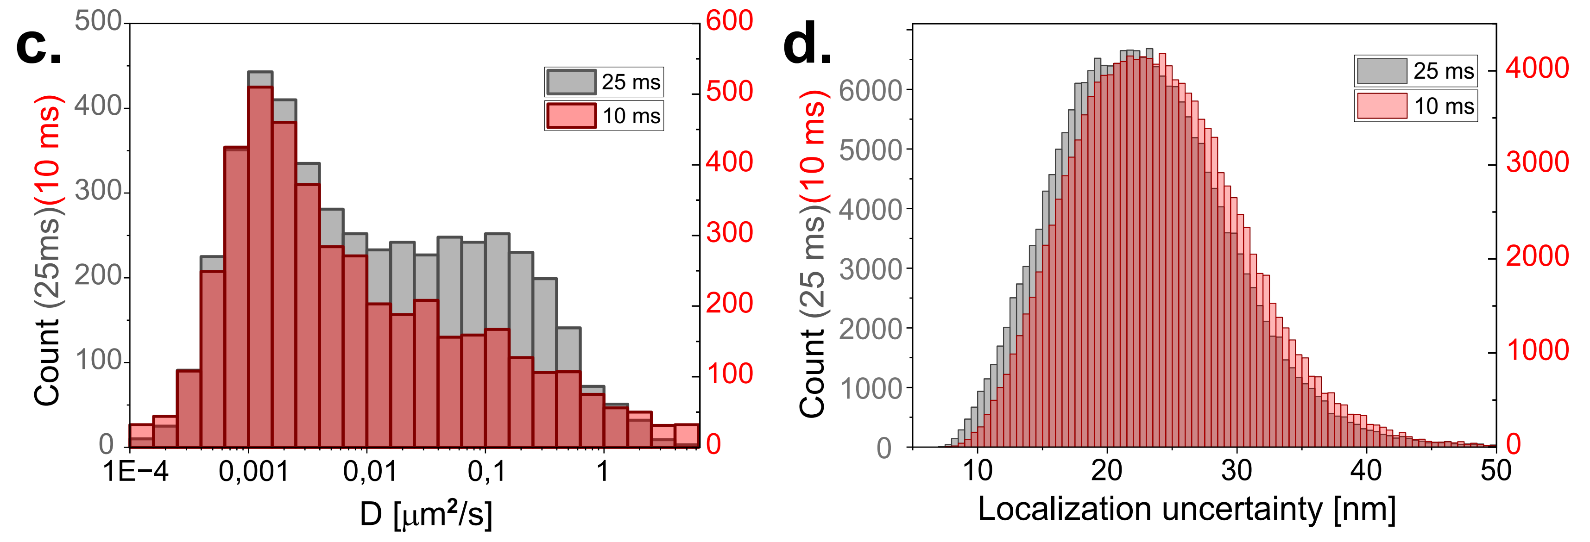
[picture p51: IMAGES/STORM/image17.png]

Diffusion coefficient of the tracked quantum dots with 10 and 25 ms
exposure time of the camera. To have similar localization uncertainties,
the laser power was doubled for the shorter exposure time. Two
populations can be identified. The first one has a slower diffusion and
corresponds to particles which are stuck or simply immobile. The other
population which seems to have a maximum around
$D = 0,1\\frac{\\text{µm}^{2}}{s}$ and corresponds to the random
diffusion of GPI on the cell membrane.

# Super-resolution imging with *d*STORM  

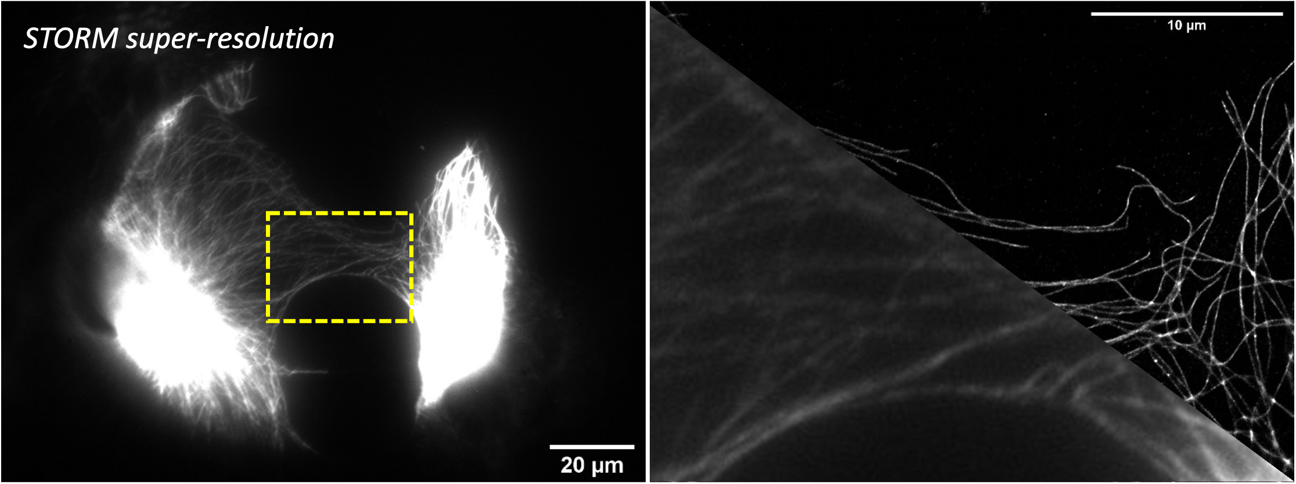
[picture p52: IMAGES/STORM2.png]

First ever *d*STORM image of microtubules reconstructed from wide-field images
acquired on the UC2 setup. Blinking, illumination intensity and exposure time were then optimized. The improved results ar displayed in the following figure.

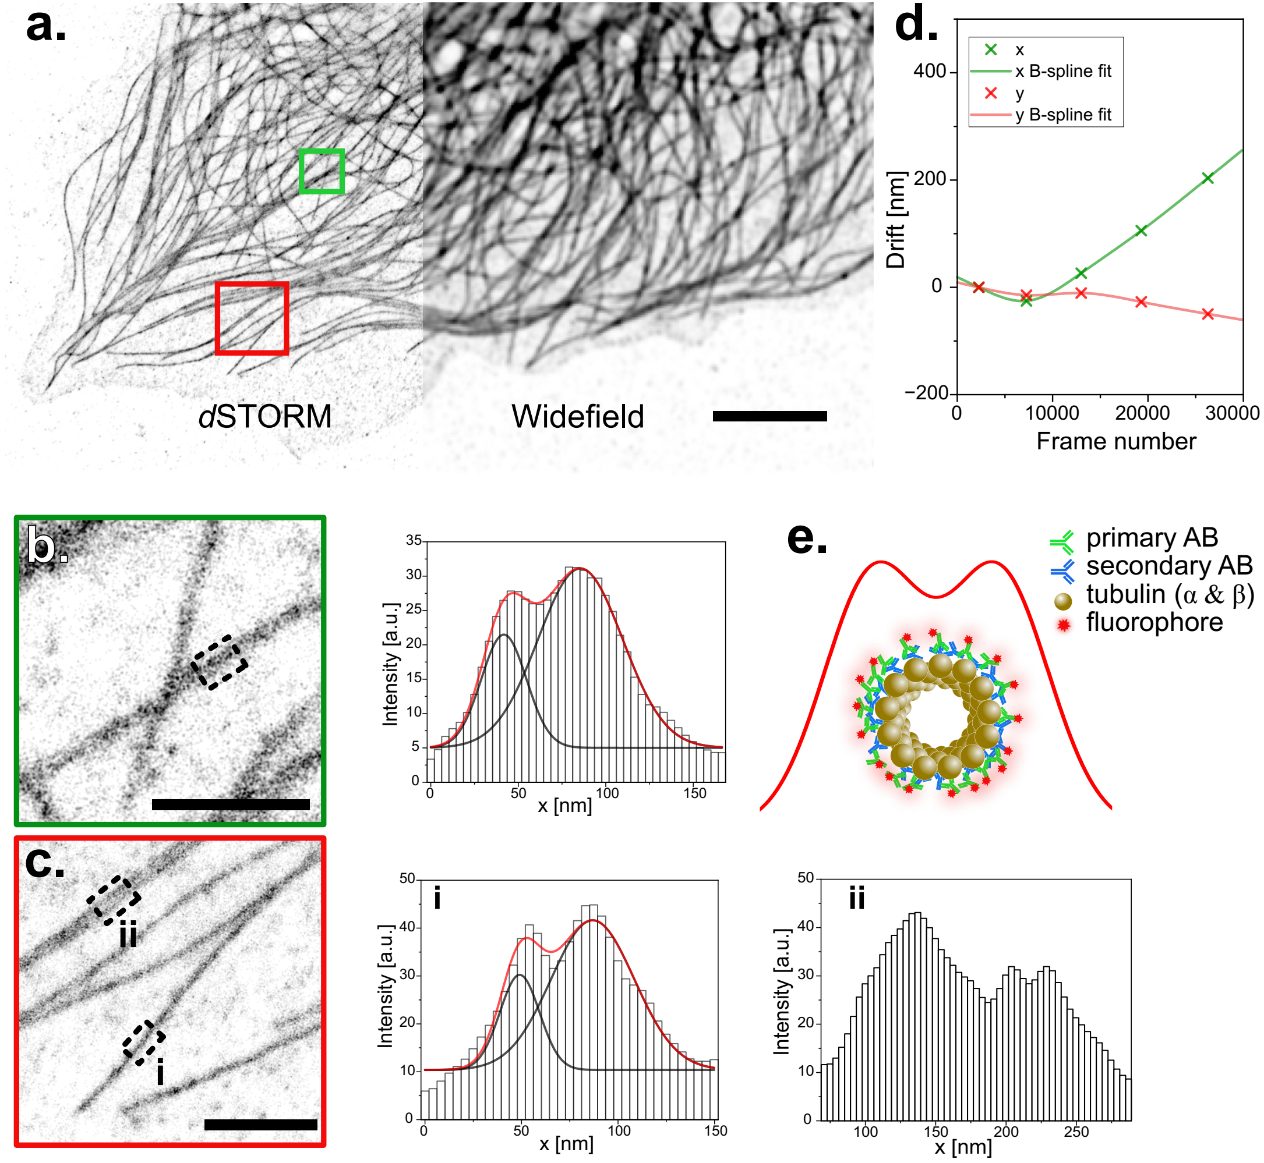
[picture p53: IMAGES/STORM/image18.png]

*d*STORM image of microtubules reconstructed from wide-field images
acquired on the UC2. **a.** Immuno-stained microtubules in CV-1 cells
are shown in wide-field and with *d*STORM. Scale bar represents 5 µm.
**b.** and **c.** show the averaged profiles along 200 nm of
microtubules within two regions of interest. Profiles are fitted with a
double Gaussian. Peak to peak distances of (38±2) nm for **b** and
(43±2) nm for **c.i** are extrapolated. Scale bar represents 1 µm in the
magnified ROIs. **d.** Drift measured by cross-correlation during the
raw-data acquisition period of the reconstructed image displayed in
**a**. **e.** Simplified schematic of the front view of a microtubule
sample after immuno-staining and the resulting railroad tracks.

## Imaging with lower-budget objectives

# Widefield comparison between high-quality and lower-budget objectives


Stable HeLa cell-line with Clathrin light chain-GFP stained with AF647
conjugated anti-GFP nanobodies, in the fluorescence as well as the
brightfield channel. Images have been acquired with the different
objectives listed in the top of the image. The scale bars in the 20 ×,
60 × and 100 × magnified images respectively represent 30 µm.

# *d*STORM using a lower budget objective

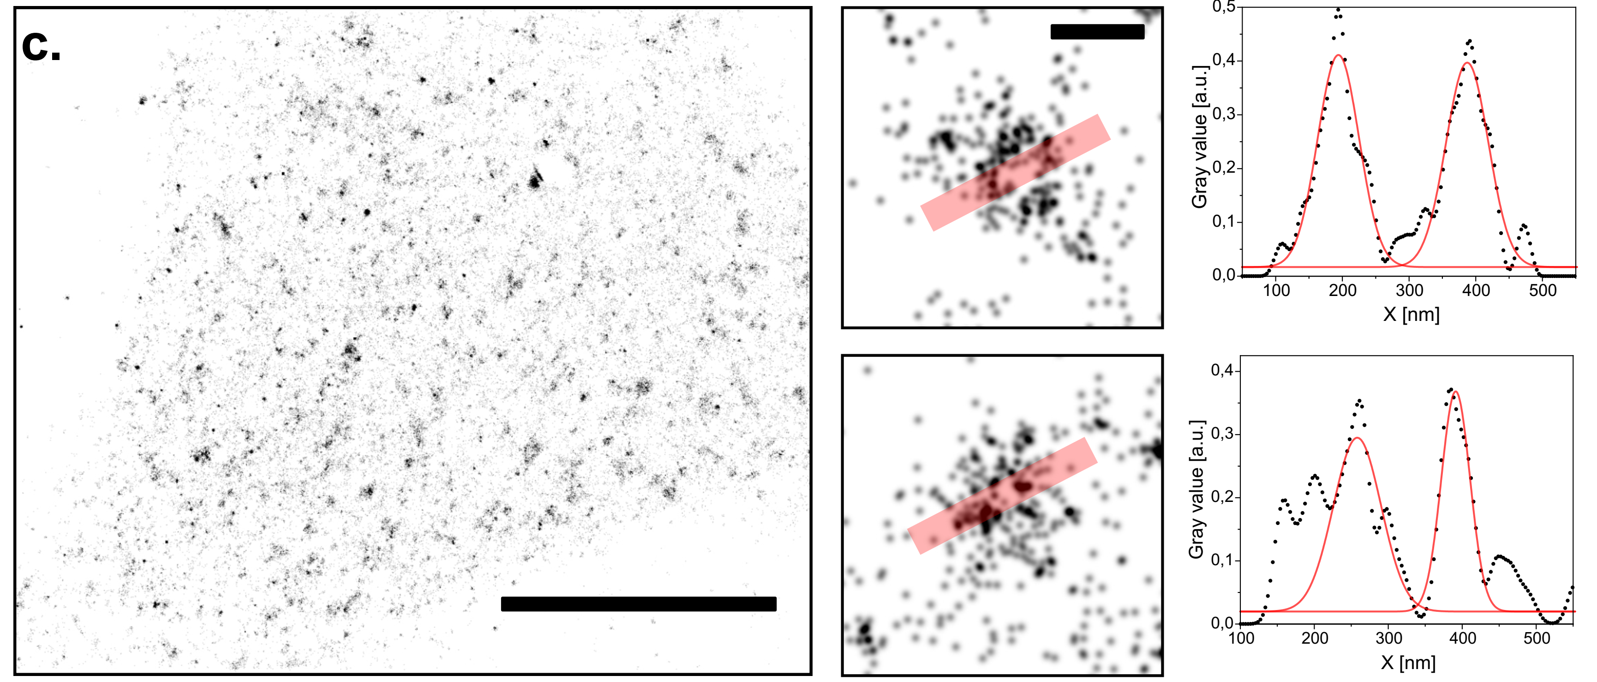
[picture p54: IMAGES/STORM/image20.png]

Single molecule localization microscopy (*d*STORM) on the UC2 setup with
a low-budget objective. Reconstruction of CLC-GFP in HeLa cells
immuno-stained with AF647 conjugated nanobodies. Scale bar for
represents 10 µm. Two CCPs have been zoomed in to plot the profiles
along the red transparent line. Scale bar for the magnified regions of
interest represents 200 nm.

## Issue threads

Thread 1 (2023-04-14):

Different comments

AZehrer, 2023-04-14:
@beniroquai

- Wir sollten noch die BOM einfügen?
- Soll ich noch etwas zum Aufbau des Setups schreiben?
- Wahrscheinlich wäre eine kleine Einleitung zum ImSwitch GUI ganz gut. Die installation findet man schon auf dem haupt repository oder?
- Ich hab für die Messungen im Inkubator den fiber laser verwendet. Sollen wir den auch hier erwähnen. bzw. die verschiedeenn kombis, also nur laser für STORM und SPT, dann laser mit teleskop und diffuser oder Fiber laser für den rest. Also vielleicht extra BOM für die laser?
-

beniroquai, 2023-04-18:
@AZehrer thanks! Would you mind to open one issue per issue? ;-)
Thank you! :)

beniroquai, 2023-04-19:
great..waiting for it ^^

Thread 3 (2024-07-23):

Doubt

matiashl27, 2024-07-23:
Hello Benedict, I have been working for a while with the **UC2** models, could you explain to me which are the main differences in terms of functionality of these 3 Kinematic Mirrors?
**1**
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
**2**
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
**3**
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

Regards.

beniroquai, 2024-07-23:
There is no real difference. The fully integrated version (1) is probably the best choice. We were experimenting with threaded inserts to have better stability. May work better sometimes :)

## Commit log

2023-04-10 Adding Inventor Files, STL and first figures
    [00_0-ring.ipt, 00_Arduino_CNC_Assembly.iam, 00_BallMagnets_5mm_single.ipt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]
2023-04-18 Adding BOM
2023-10-26 Update README.md
    description of the assembly image
2023-10-26 Adding assembly gif
